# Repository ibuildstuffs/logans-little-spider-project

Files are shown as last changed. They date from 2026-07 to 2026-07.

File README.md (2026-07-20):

# Logan's Little Spider Project - Single-Leg Controller

Code for controlling and testing one three-servo leg of a custom hexapod robot.
The Arduino handles inverse kinematics and servo motion. The Python tools provide
a draggable 3D controller and a simpler command dashboard.

## Prototype

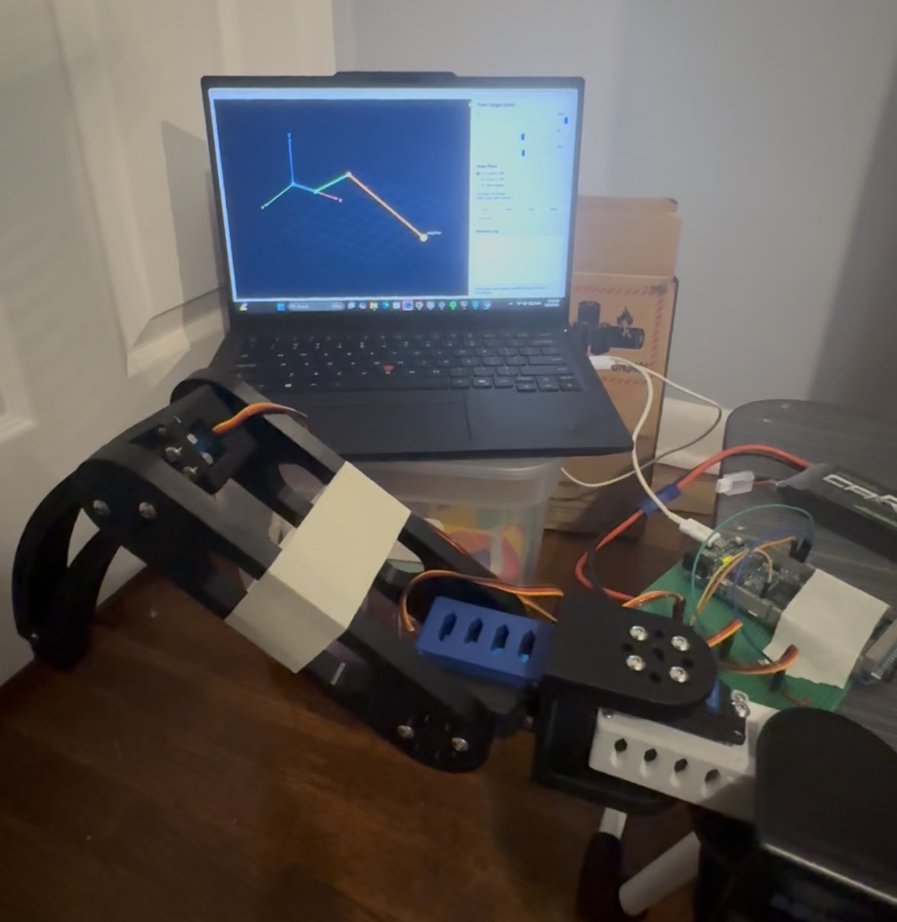
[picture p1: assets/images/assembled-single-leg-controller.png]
Assembled single-leg prototype beside the Arduino Due and 3D inverse-kinematics controller


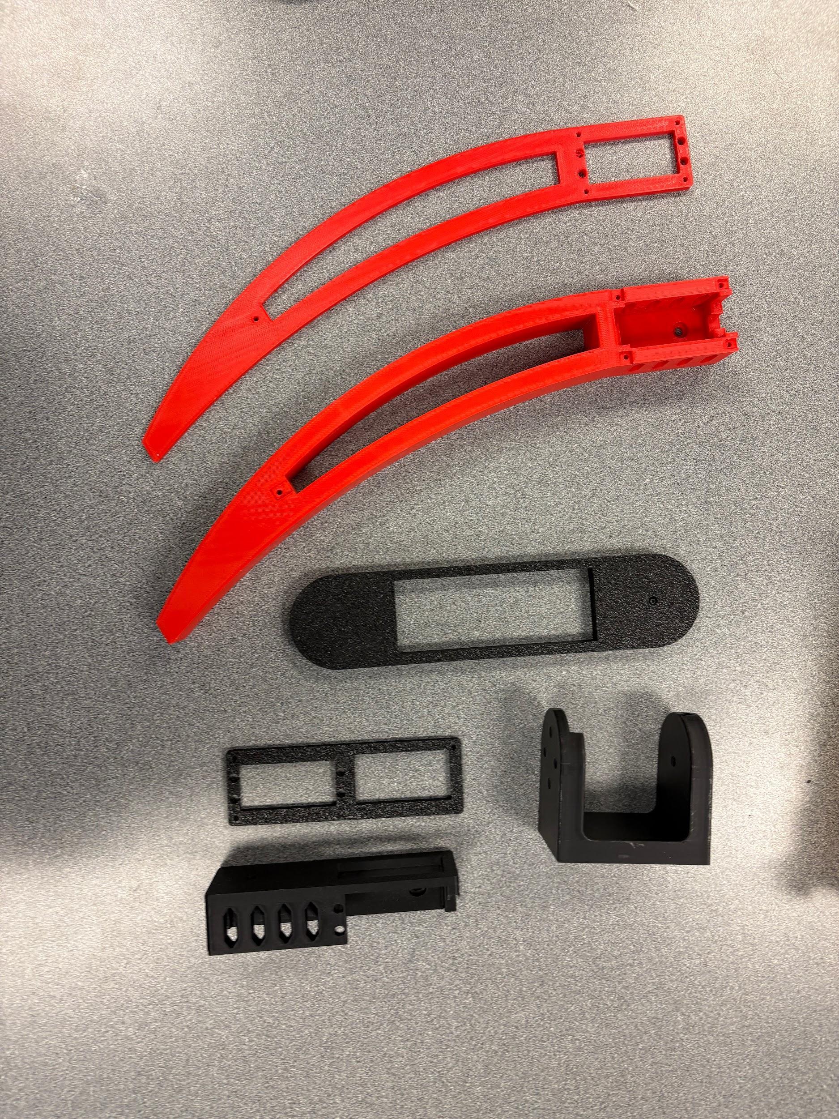
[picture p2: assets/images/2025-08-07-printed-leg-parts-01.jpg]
3D-printed leg components laid out before assembly


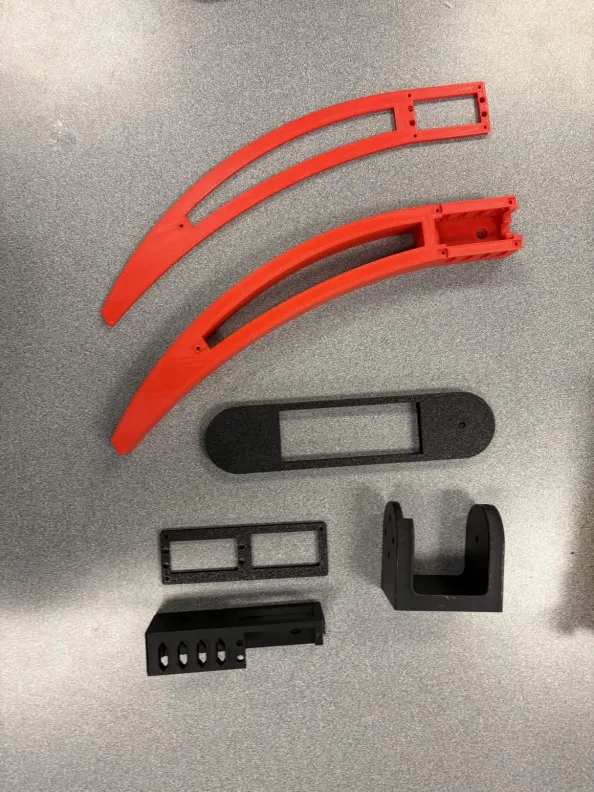
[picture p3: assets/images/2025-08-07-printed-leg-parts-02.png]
Second view of the 3D-printed leg components


## Repository layout

- `code/` - Arduino firmware, joint calibration sketch, and Python controllers
- `assets/bom.csv` - parts used in the working single-leg prototype
- `assets/cad/` - STL exports for the individual parts, servo reference, and full model

## Run the controller

Upload `code/leg_prototype/leg_prototype.ino` in Arduino IDE. The servo signal
pins are coxa `8`, femur `9`, and tibia `10`. Power the servos from a separate
supply and connect its ground to Arduino ground.

Install the Python serial dependency and run the 3D controller, replacing
`COM5` with the Arduino port:

```powershell
python -m pip install pyserial
python .\code\leg_controller.py --port COM5
```

Run the visualizer without hardware:

```powershell
python .\code\leg_controller.py --simulate
```

Open the simpler command dashboard with:

```powershell
python .\code\command_dashboard.py --port COM5
```

For unloaded, joint-by-joint calibration, upload
`code/joint_servo_test/joint_servo_test.ino` first. Use `CENTER`, `TEST COXA`,
`TEST FEMUR`, `TEST TIBIA`, and `RAW <joint> <angle>` from Serial Monitor at
`115200` baud.

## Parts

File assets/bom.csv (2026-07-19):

category | part | quantity | purpose | notes
Controller | Arduino Due | 1 | Runs inverse kinematics and sends signals to the three servos | Programming Port or Native USB can be used
Actuator | DS3235SG 35 kg high-torque servo | 3 | Coxa femur and tibia joints | Exact purchased variant should be checked against the servo label
Power | 7.4 V 2S LiPo battery | 1 | External servo power supply | OVONIC battery recorded in the project log
Mechanical | 3D-printed leg assembly | 1 | Coxa femur tibia and servo-mount structure | STL exports belong in assets/cad
Wiring | Jumper wires and power leads | 1 set | Servo signals shared ground and battery connection | Only the wiring used in the working prototype is included
Fastener | 2-56 square nuts | 1 pack | Fastens the smaller printed components | McMaster-Carr 94855A279 - https://www.mcmaster.com/94855A279/
Fastener | 2-56 screws | 1 pack | Pairs with the 2-56 square nuts in the printed assembly | McMaster-Carr 92949A079 - https://www.mcmaster.com/92949A079/
Fastener | M4 hex nuts | 1 pack | Fastens the main leg structure and joints | McMaster-Carr 90591A255 - https://www.mcmaster.com/90591A255/
Fastener | M4 screws | 1 pack | Pairs with the M4 hex nuts in the main leg structure | McMaster-Carr 92095A192 - https://www.mcmaster.com/92095A192/
Bearing | Miniature bearings | 1 pack | Supports the leg joints and reduces friction | Amazon B0G34JLXLK - https://www.amazon.com/dp/B0G34JLXLK

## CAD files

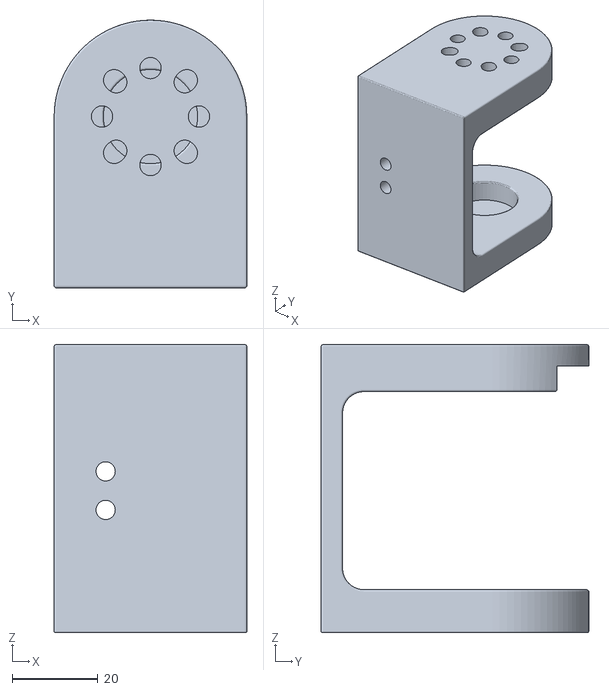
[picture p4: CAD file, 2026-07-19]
assets/cad/hip-coxa-bracket.stl
45.0 x 62.5 x 67.2

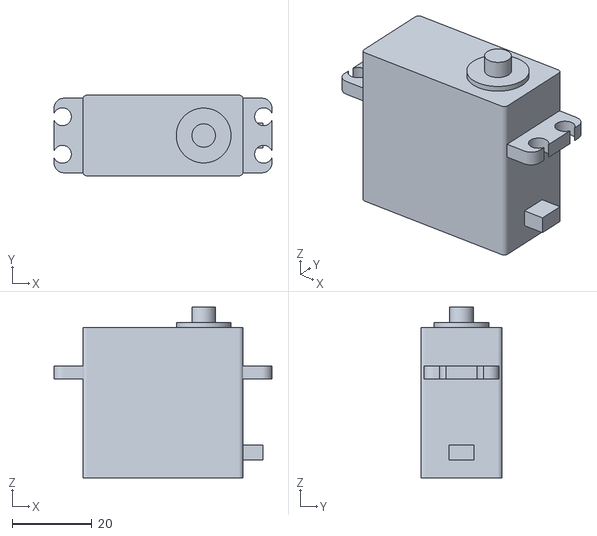
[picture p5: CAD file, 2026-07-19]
assets/cad/servo-model.stl
54.6 x 20.2 x 42.8

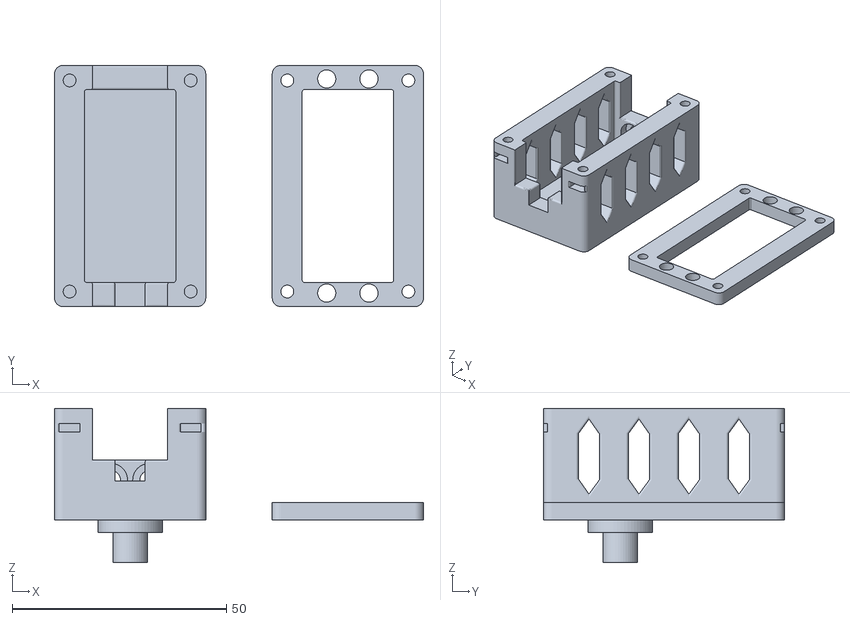
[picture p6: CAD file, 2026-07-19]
assets/cad/servo-holder-v3.stl
86.1 x 56.3 x 36.0

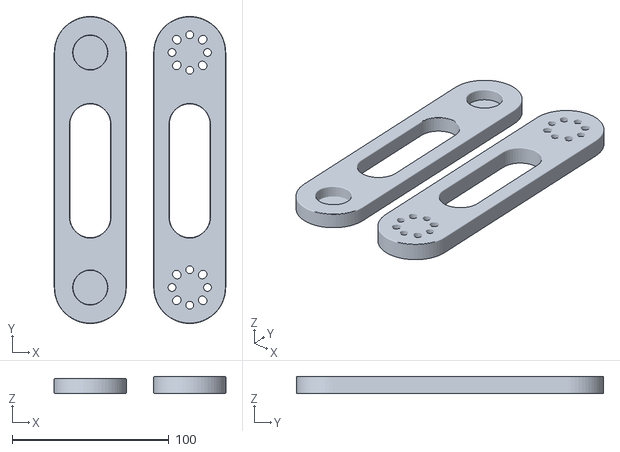
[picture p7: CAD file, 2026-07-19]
assets/cad/thigh-femur.stl
109.5 x 196.0 x 11.0

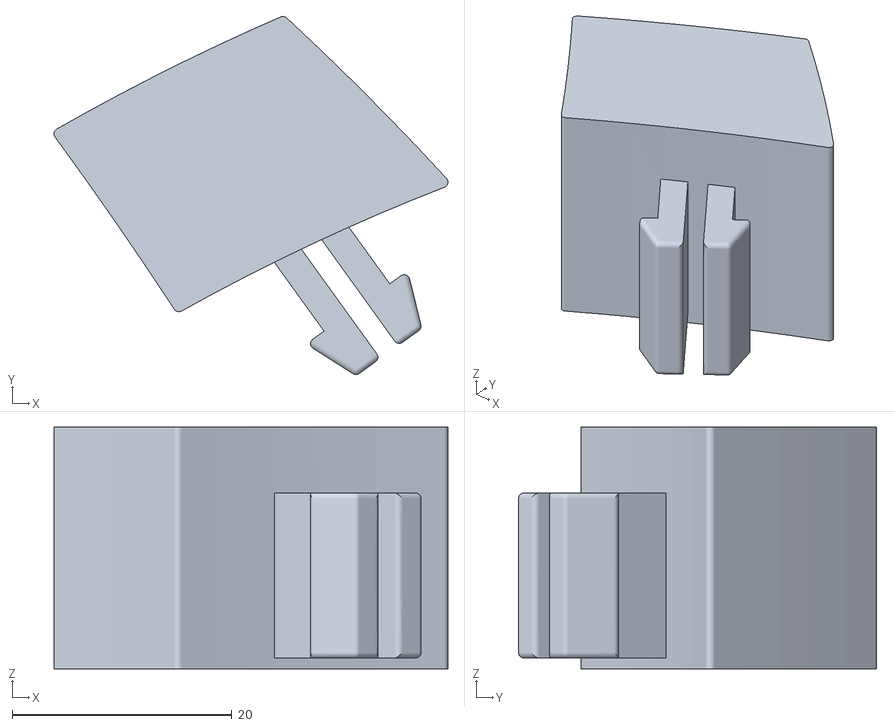
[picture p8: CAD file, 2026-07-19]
assets/cad/foot-tarsus.stl
35.8 x 32.6 x 22.0

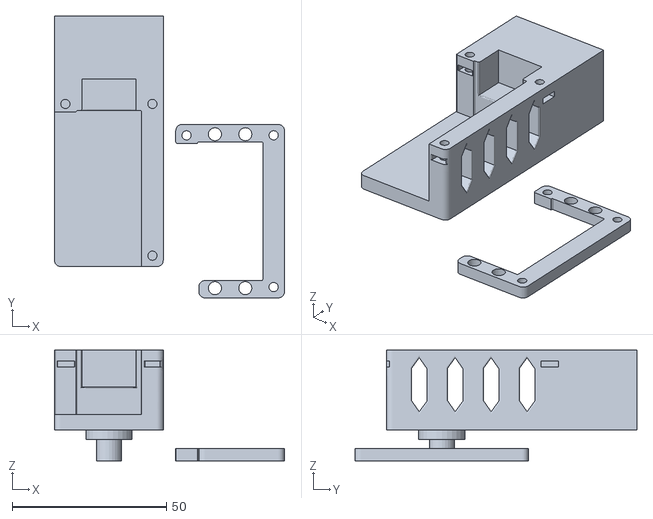
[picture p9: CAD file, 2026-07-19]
assets/cad/body.stl
74.6 x 91.5 x 36.0

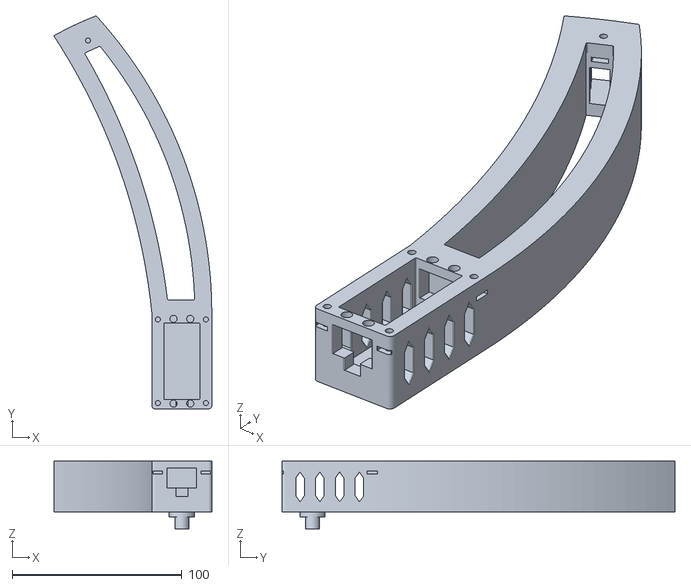
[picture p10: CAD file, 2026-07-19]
assets/cad/shin-tibia.stl
92.9 x 231.6 x 40.0

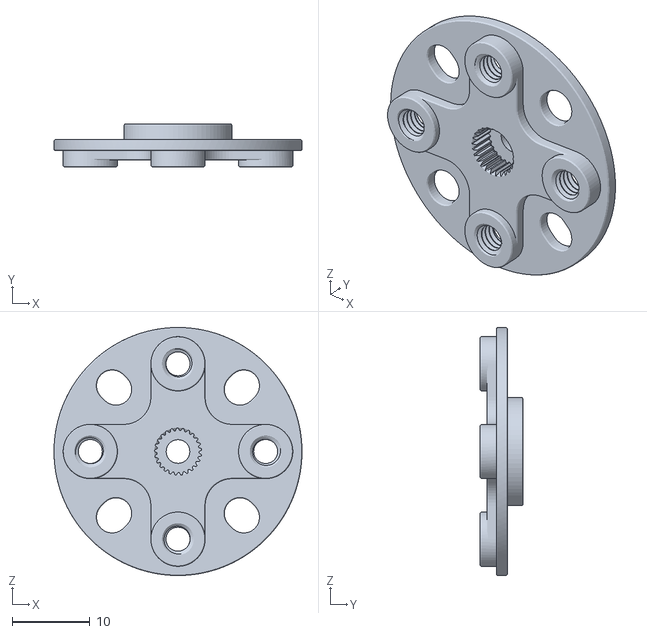
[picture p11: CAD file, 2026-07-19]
assets/cad/servo-hub.stl
32.0 x 5.50 x 32.0

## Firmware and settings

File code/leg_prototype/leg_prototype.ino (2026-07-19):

#include <Servo.h>
#include <ctype.h>
#include <math.h>
#include <stdlib.h>
#include <string.h>

// Pin assignment.
const byte COXA_PIN = 8;
const byte FEMUR_PIN = 9;
const byte TIBIA_PIN = 10;

// Leg dimensions in millimeters. Measure pivot-to-pivot for each segment.
const float COXA_LENGTH = 74.97f;
const float FEMUR_LENGTH = 150.0f;
const float TIBIA_LENGTH = 284.4615f;

// Servo command mapping. These are raw Servo.write() degree offsets.
// Your calibrated servos use 0 = left, 90 = center, 180 = right.
const float COXA_ZERO_DEG = 90.0f;
const float COXA_DIRECTION = -1.0f;
const float FEMUR_ZERO_DEG = 90.0f;
const float FEMUR_DIRECTION = -1.0f;
const float TIBIA_ZERO_DEG = 90.0f;
const float TIBIA_DIRECTION = -1.0f;

const unsigned long DEFAULT_MOVE_MS = 400;
const unsigned long STANCE_MS = 650;
const unsigned long SWING_MS = 580;
const unsigned long APPROACH_MS = 450;
const float SWING_HEIGHT = 100.0f;

struct Position {
  float x;
  float y;
  float z;
};

// x is outward from the body, y is forward/backward, and positive z is up.
const Position HOME = {450.0f, 0.0f, -30.0f};
const Position GAIT_FRONT = {450.0f, 60.0f, -30.0f};
const Position GAIT_REAR = {450.0f, -60.0f, -30.0f};

enum MotionMode {
  IDLE,
  MANUAL_MOVE,
  WALK_CYCLE
};

Servo coxa;
Servo femur;
Servo tibia;

Position currentPosition = HOME;
Position segmentStart = HOME;
Position segmentTarget = HOME;
unsigned long segmentStartTime = 0;
unsigned long segmentDuration = 0;
bool segmentActive = false;
bool segmentIsParabolicSwing = false;
MotionMode motionMode = IDLE;
byte walkPhase = 0;
int walkCyclesLeft = 0;
bool walkContinuously = false;
bool currentPositionKnown = true;

char inputBuffer[80];
byte inputLength = 0;

#ifdef USBCON
#define LOG_PORT SerialUSB
#else
#define LOG_PORT Serial
#endif

float radiansToDegrees(float radians) {
  return radians * 180.0f / PI;
}

bool calculateServoAngles(const Position &position, float &coxaAngle, float &femurAngle, float &tibiaAngle) {
  float horizontal = sqrt(position.x * position.x + position.y * position.y);
  float planar = horizontal - COXA_LENGTH;
  float distance = sqrt(planar * planar + position.z * position.z);
  float minReach = fabs(TIBIA_LENGTH - FEMUR_LENGTH);
  float maxReach = TIBIA_LENGTH + FEMUR_LENGTH;

  if (horizontal <= COXA_LENGTH || distance < minReach || distance > maxReach) {
    return false;
  }

  float femurCos = (FEMUR_LENGTH * FEMUR_LENGTH + distance * distance -
                    TIBIA_LENGTH * TIBIA_LENGTH) /
                   (2.0f * FEMUR_LENGTH * distance);
  float kneeCos = (FEMUR_LENGTH * FEMUR_LENGTH + TIBIA_LENGTH * TIBIA_LENGTH -
                   distance * distance) /
                  (2.0f * FEMUR_LENGTH * TIBIA_LENGTH);
  femurCos = constrain(femurCos, -1.0f, 1.0f);
  kneeCos = constrain(kneeCos, -1.0f, 1.0f);

  float yawDegrees = radiansToDegrees(atan2(position.y, position.x));
  float femurDegrees = radiansToDegrees(atan2(position.z, planar) + acos(femurCos));
  float kneeBendDegrees = 180.0f - radiansToDegrees(acos(kneeCos));

  coxaAngle = COXA_ZERO_DEG + COXA_DIRECTION * yawDegrees;
  femurAngle = FEMUR_ZERO_DEG + FEMUR_DIRECTION * femurDegrees;
  tibiaAngle = TIBIA_ZERO_DEG + TIBIA_DIRECTION * kneeBendDegrees;

  return coxaAngle >= 0.0f && coxaAngle <= 180.0f &&
         femurAngle >= 0.0f && femurAngle <= 180.0f &&
         tibiaAngle >= 0.0f && tibiaAngle <= 180.0f;
}

bool writePosition(const Position &position) {
  float coxaAngle;
  float femurAngle;
  float tibiaAngle;
  if (!calculateServoAngles(position, coxaAngle, femurAngle, tibiaAngle)) {
    return false;
  }

  coxa.write((int)(coxaAngle + 0.5f));
  femur.write((int)(femurAngle + 0.5f));
  tibia.write((int)(tibiaAngle + 0.5f));
  return true;
}

void stopMotion() {
  segmentActive = false;
  motionMode = IDLE;
  walkContinuously = false;
}

void writeRawAngles(int coxaAngle, int femurAngle, int tibiaAngle) {
  coxa.write(constrain(coxaAngle, 0, 180));
  femur.write(constrain(femurAngle, 0, 180));
  tibia.write(constrain(tibiaAngle, 0, 180));
}

void setCurrentPosition(const Position &position) {
  currentPosition = position;
  segmentStart = position;
  segmentTarget = position;
  currentPositionKnown = true;
}

void centerServos() {
  stopMotion();
  writeRawAngles(90, 90, 90);
  Position straight = {COXA_LENGTH + FEMUR_LENGTH + TIBIA_LENGTH, 0.0f, 0.0f};
  setCurrentPosition(straight);
  LOG_PORT.println(F("OK CENTER RAW 90 90 90"));
}

void forceHome() {
  stopMotion();
  if (!writePosition(HOME)) {
    currentPositionKnown = false;
    LOG_PORT.println(F("ERR HOME position/calibration invalid"));
    return;
  }
  setCurrentPosition(HOME);
  LOG_PORT.println(F("OK HOME"));
}

bool beginSegment(const Position &target, unsigned long duration, bool parabolicSwing) {
  float ignoredCoxa;
  float ignoredFemur;
  float ignoredTibia;
  if (!currentPositionKnown) {
    LOG_PORT.println(F("ERR current position unknown; send HOME or CENTER first"));
    return false;
  }
  if (!calculateServoAngles(target, ignoredCoxa, ignoredFemur, ignoredTibia)) {
    LOG_PORT.println(F("ERR target unreachable or outside servo limits"));
    return false;
  }

  segmentStart = currentPosition;
  segmentTarget = target;
  segmentStartTime = millis();
  segmentDuration = duration;
  segmentActive = true;
  segmentIsParabolicSwing = parabolicSwing;
  return true;
}

void updateSegment() {
  if (!segmentActive) {
    return;
  }

  unsigned long elapsed = millis() - segmentStartTime;
  float progress = segmentDuration == 0 ? 1.0f : (float)elapsed / (float)segmentDuration;
  progress = constrain(progress, 0.0f, 1.0f);

  if (segmentIsParabolicSwing) {
    currentPosition.x = segmentStart.x + (segmentTarget.x - segmentStart.x) * progress;
    currentPosition.y = segmentStart.y + (segmentTarget.y - segmentStart.y) * progress;
    currentPosition.z = segmentStart.z + (segmentTarget.z - segmentStart.z) * progress +
                        SWING_HEIGHT * 4.0f * progress * (1.0f - progress);
  } else {
    // Smoothstep reduces abrupt acceleration for straight placement movements.
    float blend = progress * progress * (3.0f - 2.0f * progress);
    currentPosition.x = segmentStart.x + (segmentTarget.x - segmentStart.x) * blend;
    currentPosition.y = segmentStart.y + (segmentTarget.y - segmentStart.y) * blend;
    currentPosition.z = segmentStart.z + (segmentTarget.z - segmentStart.z) * blend;
  }

  if (!writePosition(currentPosition)) {
    segmentActive = false;
    motionMode = IDLE;
    currentPositionKnown = false;
    LOG_PORT.println(F("ERR motion crossed an invalid position"));
    return;
  }

  if (progress >= 1.0f) {
    setCurrentPosition(segmentTarget);
    segmentActive = false;
  }
}

void startManualMove(const Position &target, unsigned long duration) {
  if (beginSegment(target, duration, false)) {
    motionMode = MANUAL_MOVE;
    LOG_PORT.println(F("OK MOVING"));
  }
}

void startWalkCycle(int cycles, bool continuous) {
  walkContinuously = continuous;
  walkCyclesLeft = continuous ? 0 : constrain(cycles, 1, 100);
  walkPhase = 0;
  motionMode = WALK_CYCLE;
  if (!beginSegment(GAIT_FRONT, APPROACH_MS, false)) {
    motionMode = IDLE;
    return;
  }
  if (walkContinuously) {
    LOG_PORT.println(F("OK WALK CONTINUOUS"));
  } else {
    LOG_PORT.print(F("OK WALK "));
    LOG_PORT.println(walkCyclesLeft);
  }
}

void updateWalkCycle() {
  if (motionMode != WALK_CYCLE || segmentActive) {
    return;
  }

  if (walkPhase == 0) {
    walkPhase = 1;
    beginSegment(GAIT_REAR, STANCE_MS, false);
  } else if (walkPhase == 1) {
    walkPhase = 2;
    beginSegment(GAIT_FRONT, SWING_MS, true);
  } else {
    if (!walkContinuously) {
      walkCyclesLeft--;
    }
    if (!walkContinuously && walkCyclesLeft <= 0) {
      motionMode = IDLE;
      LOG_PORT.println(F("DONE WALK"));
    } else {
      walkPhase = 1;
      beginSegment(GAIT_REAR, STANCE_MS, false);
    }
  }
}

void printStatus() {
  float coxaAngle;
  float femurAngle;
  float tibiaAngle;
  bool positionValid = currentPositionKnown &&
                       calculateServoAngles(currentPosition, coxaAngle, femurAngle, tibiaAngle);

  LOG_PORT.print(F("POS "));
  LOG_PORT.print(currentPosition.x, 1);
  LOG_PORT.print(' ');
  LOG_PORT.print(currentPosition.y, 1);
  LOG_PORT.print(' ');
  LOG_PORT.print(currentPosition.z, 1);
  if (positionValid) {
    LOG_PORT.print(F(" ANGLES "));
    LOG_PORT.print(coxaAngle, 1);
    LOG_PORT.print(' ');
    LOG_PORT.print(femurAngle, 1);
    LOG_PORT.print(' ');
    LOG_PORT.println(tibiaAngle, 1);
  } else {
    LOG_PORT.println(F(" ANGLES UNKNOWN"));
  }
}

void printHelp() {
  LOG_PORT.println(F("Commands: MOVE x y z [milliseconds] | HOME | CENTER | RAW c f t | WALK [cycles] | STOP | STATUS | HELP"));
  LOG_PORT.println(F("HOME directly writes the home IK pose. CENTER directly writes raw 90 90 90."));
  LOG_PORT.println(F("WALK repeats until STOP; WALK cycles runs a finite number of cycles."));
  LOG_PORT.println(F("Coordinates in mm: x outward, y forward/backward, +z upward."));
}

void handleCommand(char *line) {
  char *command = strtok(line, " \t");
  if (command == NULL) {
    return;
  }
  for (char *character = command; *character; character++) {
    *character = (char)toupper(*character);
  }

  if (strcmp(command, "MOVE") == 0) {
    char *xText = strtok(NULL, " \t");
    char *yText = strtok(NULL, " \t");
    char *zText = strtok(NULL, " \t");
    char *durationText = strtok(NULL, " \t");
    if (xText == NULL || yText == NULL || zText == NULL) {
      LOG_PORT.println(F("ERR usage: MOVE x y z [milliseconds]"));
      return;
    }
    Position target = {atof(xText), atof(yText), atof(zText)};
    unsigned long duration = durationText == NULL ? DEFAULT_MOVE_MS : strtoul(durationText, NULL, 10);
    startManualMove(target, duration);
  } else if (strcmp(command, "HOME") == 0) {
    forceHome();
  } else if (strcmp(command, "CENTER") == 0) {
    centerServos();
  } else if (strcmp(command, "RAW") == 0) {
    char *coxaText = strtok(NULL, " \t");
    char *femurText = strtok(NULL, " \t");
    char *tibiaText = strtok(NULL, " \t");
    if (coxaText == NULL || femurText == NULL || tibiaText == NULL) {
      LOG_PORT.println(F("ERR usage: RAW coxa femur tibia"));
      return;
    }
    stopMotion();
    writeRawAngles(atoi(coxaText), atoi(femurText), atoi(tibiaText));
    currentPositionKnown = false;
    LOG_PORT.println(F("OK RAW"));
  } else if (strcmp(command, "WALK") == 0) {
    char *cyclesText = strtok(NULL, " \t");
    if (cyclesText == NULL) {
      startWalkCycle(0, true);
    } else {
      startWalkCycle(atoi(cyclesText), false);
    }
  } else if (strcmp(command, "STOP") == 0) {
    stopMotion();
    LOG_PORT.println(F("OK STOPPED"));
  } else if (strcmp(command, "STATUS") == 0) {
    printStatus();
  } else if (strcmp(command, "HELP") == 0) {
    printHelp();
  } else {
    LOG_PORT.println(F("ERR unknown command; send HELP"));
  }
}

void readCommandByte(char character) {
  if (character == '\n' || character == '\r') {
    if (inputLength > 0) {
      inputBuffer[inputLength] = '\0';
      handleCommand(inputBuffer);
      inputLength = 0;
    }
  } else if (inputLength < sizeof(inputBuffer) - 1) {
    inputBuffer[inputLength++] = character;
  } else {
    inputLength = 0;
    LOG_PORT.println(F("ERR command too long"));
  }
}

void readSerialCommands() {
  while (Serial.available() > 0) {
    readCommandByte((char)Serial.read());
  }
#ifdef USBCON
  while (SerialUSB.available() > 0) {
    readCommandByte((char)SerialUSB.read());
  }
#endif
}

void setup() {
  Serial.begin(115200);
#ifdef USBCON
  SerialUSB.begin(115200);
#endif
  coxa.attach(COXA_PIN);
  femur.attach(FEMUR_PIN);
  tibia.attach(TIBIA_PIN);

  forceHome();
  delay(500);
  LOG_PORT.println(F("READY LEG CONTROLLER"));
  printHelp();
}

void loop() {
  readSerialCommands();
  updateSegment();

  if (motionMode == MANUAL_MOVE && !segmentActive) {
    motionMode = IDLE;
    LOG_PORT.println(F("DONE MOVE"));
  } else {
    updateWalkCycle();
  }
}

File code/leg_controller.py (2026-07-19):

"""Interactive USB serial controller and 3D visualizer for a three-servo leg."""

from __future__ import annotations

import argparse
import math
import queue
import sys
import threading
import time
from dataclasses import dataclass
from typing import Optional

COXA_LENGTH = 74.97
FEMUR_LENGTH = 150.0
TIBIA_LENGTH = 284.4615

# Raw Servo.write() degree mapping. Calibrated servos use:
# 0 = left, 90 = center, 180 = right.
COXA_ZERO_DEG = 90.0
COXA_DIRECTION = -1.0
FEMUR_ZERO_DEG = 90.0
FEMUR_DIRECTION = -1.0
TIBIA_ZERO_DEG = 90.0
TIBIA_DIRECTION = -1.0

HOME = (450.0, 0.0, -30.0)
GAIT_FRONT = (450.0, 60.0, -30.0)
GAIT_REAR = (450.0, -60.0, -30.0)
APPROACH_MS = 450
STANCE_MS = 650
SWING_MS = 580
SWING_HEIGHT = 100.0
AXIS_LIMITS = ((80.0, 460.0), (-220.0, 220.0), (-250.0, 180.0))
DEFAULT_CAMERA_AZIMUTH_DEG = 35.0
DEFAULT_CAMERA_ELEVATION_DEG = 30.0


@dataclass
class LegSolution:
    hip: tuple[float, float, float]
    coxa: tuple[float, float, float]
    knee: tuple[float, float, float]
    foot: tuple[float, float, float]
    angles: tuple[float, float, float]


def solve_leg(position: tuple[float, float, float]) -> Optional[LegSolution]:
    """Return drawable joints and firmware-matching servo angles, or None."""
    x, y, z = position
    horizontal = math.hypot(x, y)
    planar = horizontal - COXA_LENGTH
    distance = math.hypot(planar, z)
    min_reach = abs(TIBIA_LENGTH - FEMUR_LENGTH)
    max_reach = TIBIA_LENGTH + FEMUR_LENGTH

    if horizontal <= COXA_LENGTH or distance < min_reach or distance > max_reach:
        return None

    femur_cos = (FEMUR_LENGTH**2 + distance**2 - TIBIA_LENGTH**2) / (
        2.0 * FEMUR_LENGTH * distance
    )
    knee_cos = (FEMUR_LENGTH**2 + TIBIA_LENGTH**2 - distance**2) / (
        2.0 * FEMUR_LENGTH * TIBIA_LENGTH
    )
    femur_cos = max(-1.0, min(1.0, femur_cos))
    knee_cos = max(-1.0, min(1.0, knee_cos))

    yaw = math.degrees(math.atan2(y, x))
    femur_angle = math.degrees(math.atan2(z, planar) + math.acos(femur_cos))
    knee_bend = 180.0 - math.degrees(math.acos(knee_cos))
    angles = (
        COXA_ZERO_DEG + COXA_DIRECTION * yaw,
        FEMUR_ZERO_DEG + FEMUR_DIRECTION * femur_angle,
        TIBIA_ZERO_DEG + TIBIA_DIRECTION * knee_bend,
    )
    if not all(0.0 <= angle <= 180.0 for angle in angles):
        return None

    radial_x = x / horizontal
    radial_y = y / horizontal
    coxa = (COXA_LENGTH * radial_x, COXA_LENGTH * radial_y, 0.0)

    along = (FEMUR_LENGTH**2 - TIBIA_LENGTH**2 + distance**2) / (2.0 * distance)
    height = math.sqrt(max(0.0, FEMUR_LENGTH**2 - along**2))
    local_knee_out = along * planar / distance - height * z / distance
    local_knee_z = along * z / distance + height * planar / distance
    knee_radius = COXA_LENGTH + local_knee_out
    knee = (knee_radius * radial_x, knee_radius * radial_y, local_knee_z)

    return LegSolution((0.0, 0.0, 0.0), coxa, knee, position, angles)


class SerialTransport:
    def __init__(self, port: Optional[str], baud: int, simulate: bool) -> None:
        self.responses: queue.Queue[str] = queue.Queue()
        self.connection = None
        self.stopped = threading.Event()
        self.write_lock = threading.Lock()
        self.simulate = simulate

        if simulate:
            self.responses.put("SIMULATION MODE: movements are not sent to an Arduino.")
            return

        try:
            import serial
        except ImportError:
            raise RuntimeError("pyserial is required. Install it with: python -m pip install pyserial")

        if not port:
            raise RuntimeError("A serial port is required unless --simulate is used, for example --port COM5.")
        try:
            self.connection = serial.Serial(port, baud, timeout=0.1)
        except serial.SerialException as error:
            raise RuntimeError(f"Could not open or use {port}: {error}") from error

        time.sleep(2.0)  # Most Arduino boards reset when their serial port opens.
        threading.Thread(target=self._read_responses, daemon=True).start()

    def _read_responses(self) -> None:
        while not self.stopped.is_set() and self.connection is not None:
            raw = self.connection.readline()
            if raw:
                self.responses.put(raw.decode(errors="replace").rstrip())

    def send(self, command: str, log: bool = True) -> None:
        if self.simulate:
            if log:
                self.responses.put(f"> {command}")
            return
        if self.connection is None:
            return
        with self.write_lock:
            self.connection.write((command + "\n").encode("ascii"))
            self.connection.flush()
        if log:
            self.responses.put(f"> {command}")

    def close(self) -> None:
        self.stopped.set()
        if self.connection is not None:
            self.connection.close()
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
